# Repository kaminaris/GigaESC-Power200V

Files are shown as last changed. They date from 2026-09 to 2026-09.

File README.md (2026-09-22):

# GigaPower200V

Compact 50 × 20 mm non-isolated power-supply module for the modular GigaESC platform, intended for the 200 V version. Provides 12 V, 5 V and 3.3 V rails through a separate output connector.

## Board views

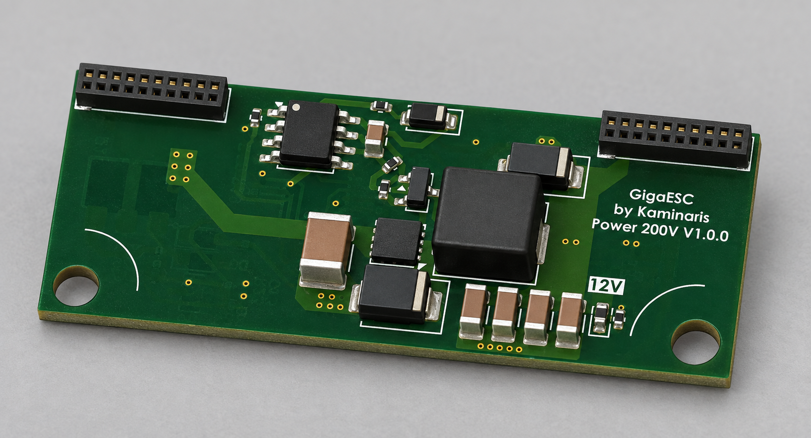
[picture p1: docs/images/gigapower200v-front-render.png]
GigaPower200V front view


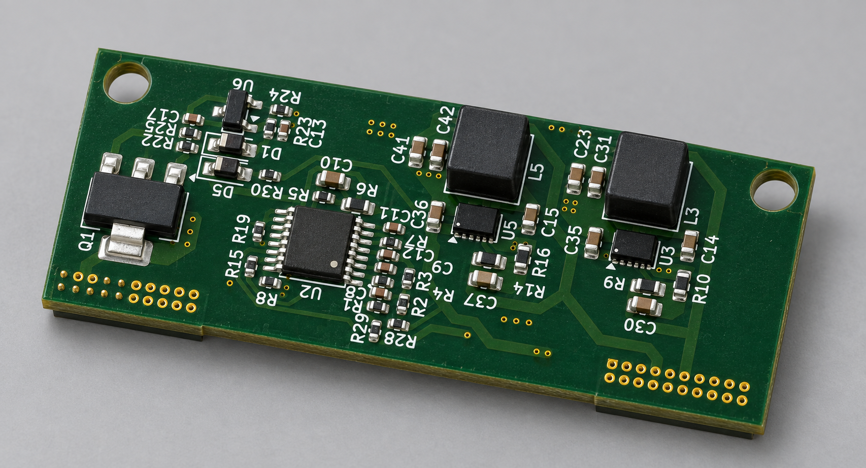
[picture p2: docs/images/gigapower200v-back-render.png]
GigaPower200V back view


## Hardware

- TL494 PWM controller, IR2181 gate driver and TL431 reference circuitry.
- Two AP63356DV buck regulators for the lower-voltage rails.
- Two 2×10 connectors separating input and output connections.
- Common ground between input and outputs; no galvanic isolation.

## Connector summary

| Connector | Pins | Signal |
|---|---|---|
| J1 input | 3, 5 | VIN |
| J1 input | 17–20 | GND |
| J2 output | 3, 4 | 12 V |
| J2 output | 7, 8 | 5 V |
| J2 output | 11, 12 | 3.3 V |
| J2 output | 1, 2, 5, 6, 9, 10, 13–16, 19, 20 | GND |

Remaining connector pins are unconnected in the schematic. Use the current schematic as the authoritative pinout.

## Project

Open `GigaPower200V.kicad_pro` in KiCad 10. Schematic and layout are in `GigaPower200V.kicad_sch` and `GigaPower200V.kicad_pcb`. Local libraries are included; keep the connector STEP model alongside the project.

The project name describes the intended voltage class, not a measured operating limit. Input range, output loading and thermal performance require hardware validation. The inherited `LM5164_DESIGN.md` describes an earlier design and is not documentation for the current TL494 implementation.

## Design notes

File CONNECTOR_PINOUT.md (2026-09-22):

# GigaControl connector pinout

Three 2x10, 1.00 mm pitch straight female sockets on the control card: Hanxia HX PM1.0-2x10P ZC, LCSC C22465702. Matching proposed right-angle male headers on the power board: HX PZ1.0-2x10P WZ, C22465711.

F.Cu view: J1, J2, J3 left to right; odd row at Y=88.1, even row at Y=87.1. Pad-1 X positions: 138.1, 150.1, 162.1 mm. Three sockets span 34.4 mm of nominal housing length. Phase contacts and connector positions are preserved. Three reserved interface contacts have been reclaimed for GND; active peripheral signals retain their numeric sequence while shifting pins.

J3 GND contacts: pins 1, 10, and 20 (left, middle, right). Peripheral remapping starts at J2 pin 17; the table below is authoritative.

| Column | Connector | Odd pin | Signal | Even pin | Signal |
|---:|---|---:|---|---:|---|
| 1 | J1 | 1 | `+5V` | 2 | `GND` |
| 2 | J1 | 3 | `+3.3V` | 4 | `IN V` |
| 3 | J1 | 5 | `POWER STAGE DISABLE` | 6 | `POWER STAGE LOCKOUT` |
| 4 | J1 | 7 | `MOSTEMP3` | 8 | `GND` |
| 5 | J1 | 9 | `H3` | 10 | `GND` |
| 6 | J1 | 11 | `L3` | 12 | `GND` |
| 7 | J1 | 13 | `CURR3 FILTERED` | 14 | `GND` |
| 8 | J1 | 15 | `VSENSE3` | 16 | `GND` |
| 9 | J1 | 17 | `MOSTEMP2` | 18 | `GND` |
| 10 | J1 | 19 | `H2` | 20 | `GND` |
| 11 | J2 | 1 | `L2` | 2 | `GND` |
| 12 | J2 | 3 | `CURR2 FILTERED` | 4 | `GND` |
| 13 | J2 | 5 | `VSENSE2` | 6 | `GND` |
| 14 | J2 | 7 | `MOSTEMP1` | 8 | `GND` |
| 15 | J2 | 9 | `H1` | 10 | `GND` |
| 16 | J2 | 11 | `L1` | 12 | `GND` |
| 17 | J2 | 13 | `CURR1 FILTERED` | 14 | `GND` |
| 18 | J2 | 15 | `VSENSE1` | 16 | `GND` |
| 19 | J2 | 17 | `USBD-` | 18 | `USBD+` |
| 20 | J2 | 19 | `SWDIO` | 20 | `HALL3 IN` |
| 21 | J3 | 1 | `GND` | 2 | `SERVO` |
| 22 | J3 | 3 | `I2C2 SDA{slash}USART3 RX` | 4 | `ESP-RX` |
| 23 | J3 | 5 | `SPI1-MISO-ADC2` | 6 | `SPI1-SCK-ADC` |
| 24 | J3 | 7 | `HALL1 IN` | 8 | `HALL-VOLTAGE` |
| 25 | J3 | 9 | `I2C2 SCL{slash}USART3 TX` | 10 | `GND` |
| 26 | J3 | 11 | `SPI1-NSS` | 12 | `NRST` |
| 27 | J3 | 13 | `HALL2 IN` | 14 | `ESP-TX` |
| 28 | J3 | 15 | `SPI1-MOSI` | 16 | `IN-CANL` |
| 29 | J3 | 17 | `TEMPMOTOR IN` | 18 | `IN-CANH` |
| 30 | J3 | 19 | `SWCLK` | 20 | `GND` |

Phase 3: columns 4-8; phase 2: 9-13; phase 1: 14-18. All 41 active non-ground signals retained, with 19 ground contacts. RESERVED1/2/3 no longer cross the connector; their MCU-side circuitry is unchanged.

## Mechanical notes

- Local socket footprint follows the Hanxia drawing: body 10.4 x 2.5 mm, height 2 mm, 1 x 1 mm pin grid, 0.50 mm finished holes. Pads are 0.8 mm; courtyard includes body tolerance plus assembly clearance. No 3D model is assigned.
- Numbering is the project logical odd/even convention; the unkeyed manufacturer drawing does not define pin 1. Power-board mating placement must map contacts physically, not copy the control footprint rotation blindly.
- Upright card inserts horizontally with right-angle male pins on the horizontal power board. Allow withdrawal clearance and provide a guide/support; do not rely on the three connectors for vibration support.
- Header drawing has 0.30 mm square contacts and 2.00 mm nominal horizontal exposed tips; the 1.8 mm dimension is vertical tail projection. Socket drawing does not specify a recommended mating-pin insertion range; verify engagement with samples before manufacture.
- Connector fanout remains unfinished; moving pads does not reroute existing traces. No raw battery voltage crosses the interface.

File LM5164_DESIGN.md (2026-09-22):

# LM5164 design — 20–90 V to nominal 12 V / 1 A

Schematic design pass, 2026-09-16. Not a production-qualified supply. Typical reported system consumption is about 2 W; retain 12 W output design target including downstream converters. No PCB changes in this pass.

## Selected components and inventory

| References | Value / part | Inventory / decision |
|---|---|---|
| U1 | LM5164DDAR | Not found; order |
| L4 | 68 uH MSS1210-683MEB | WEBENCH baseline, not stocked; correct Coilcraft footprint replaces unrelated 5 mm placeholder |
| R11 | 100k 0603WAF1003T5E | Stock C25803, R20, qty 200 |
| R12 | 453k RC0603FR-07453KL | WEBENCH value, not stocked |
| R13 | 50k RT0603BRD0750KL | WEBENCH value, not stocked |
| R17 / R18 | 150k + 200k, 0603 | Stock C22807 / C25811, R20; total 350k instead of WEBENCH 357k |
| C2 / C6 | 2.2 nF 50 V X7R 0603B222K500NT | Stock C1604, C1, qty 100 |
| C7 | 47 pF NP0 CC0603FRNPO0BN470 | Stock C527044, C1, qty 50 |
| C1 / C4 | 10 uF 100 V X7R FS32X106K101EGG, 1210 | Stock C5156756, C2, qty 32. PROVISIONAL pending DC-bias data |
| C3 / C5 | 22 uF 25 V X5R CL31A226KAHNNNE, 1206 | Stock C12891, C2, qty 10. Verify effective capacitance and local temperature; X5R is rated only to 85 C |

Counts are database qty, not qty minus inUse. No inventory was reserved or modified. The stock CYA0650-68UH (C5189964, qty 4, inUse 1, bin L1) remains an alternative, not an approved replacement: its specific datasheet could not be retrieved and the accessible family sheet does not list 68 uH. The 1.8 A catalog rating alone does not establish saturation margin. The other stocked 68 uH YSPI1365 is large and also needs a verified saturation specification.

## Calculated operating points

First-order CCM calculations at nominal 300 kHz, 68 uH, 12 V. These are calculations, not simulations or measurements.

| VIN | Duty | On time | Inductor ripple p-p | Peak at 1 A | Injected ramp estimate |
|---|---:|---:|---:|---:|---:|
| 20 V | 0.600 | 2.00 us | 0.235 A | 1.118 A | 20.8 mV |
| 48 V | 0.250 | 0.833 us | 0.441 A | 1.221 A | 39.0 mV |
| 90 V | 0.133 | 0.444 us | 0.510 A | 1.255 A | 45.0 mV |

At minus 20% inductance, 90 V ripple becomes 0.637 A p-p and peak 1.319 A, before switching-frequency tolerance, temperature, or DC-bias loss of inductance. Qualify saturation against the regulator current limit, not merely 1.319 A normal-load peak.

The 350k * 2.2nF network has a 770 us time constant, 2% below WEBENCH. Splitting it limits nominal 90 V switching-step resistor stress to about 33.4 V / 44.6 V across 150k / 200k once the ramp node is near 12 V; at startup with the ramp node near zero the split is about 38.6 V / 51.4 V. Check overshoot and actual resistor pulse ratings during bring-up.

The divider's ideal zero-ripple setpoint is 12.072 V. Ripple injection, reference/divider tolerances and operating mode affect the actual DC output. Do not describe this as precision 12.000 V. The 47 pF coupling choice is retained from WEBENCH; transient response needs bench validation with the downstream converters attached.

At roughly 0.167 A load, the LM can enter discontinuous / pulse-skipping operation at higher VIN. The 1 A current target does not imply continuous-conduction operation at typical load. The prior 9 mW small-inductor loss estimate excludes ripple; it is not a complete light-load loss prediction.

## Qualification and integration remaining

- C1/C4 must retain at least 2.2 uF total at 90 V, with tolerance, temperature and aging allowed for. 20 uF nominal is NOT evidence of that. No usable part-specific bias curve was obtained. If not verified, use a documented higher-voltage capacitor rather than relying on this provisional stock selection. WEBENCH's 450 V parts were not copied into the small-board design.
- C3/C5 target at least 10 uF effective total at 12 V. At that assumed minimum, nominal worst-case capacitive ripple is about 21 mV p-p (excluding ESR/transients). Stock X5R parts constrain local temperature to <=85 C; use X7R replacements if that is insufficient.
- 90 V DC leaves only 10 V to the IC's 100 V absolute maximum. VBAT is currently an explicit local net, not connected to the unassigned J2 connector. Battery leads, main-board bulk capacitance, hot-plug damping and regeneration overshoot must be addressed at integration. Do not assume an ordinary 90 V TVS clamps below 100 V.
- EN remains tied to VIN as in WEBENCH. No battery undervoltage cutoff is implied by the 20 V design minimum. PGOOD intentionally remains unconnected.
- Ground EP and keep the input switching loop short. Route the divider/ripple network away from SW copper and return it to quiet IC ground. Validate output ripple, load steps, startup, fault behavior and temperatures at both input extremes.
- PCB placement/routing and connector pin assignment are not part of this schematic pass. Reconcile the schematic with the PCB after component qualification.

## Sources

- User-provided WBSchematicLM5164DDAR.svg and WBBOMDesignLM5164DDAR.csv.
- TI LM5164 datasheet: https://www.ti.com/lit/ds/symlink/lm5164.pdf
- Coilcraft baseline inductor: https://www.coilcraft.com/getmedia/f1a1bc5f-bdff-42f8-9ca8-1a0fb1d5094f/MSS1210.pdf
- Samsung stock output capacitor: https://product.samsungsem.com/mlcc/CL31A226KAHNNN.do
- Read-only local bommanager inventory snapshot.

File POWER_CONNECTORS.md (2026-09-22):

# GigaPower100V supply module — J1 / J2 pinout

Two 2x10, 1.00 mm pitch connectors (Hanxia HX PM1.0-2x10P ZC, LCSC C22465702; mating
HX PZ1.0-2x10P WZ, C22465711). **J1 carries the battery bus, J2 carries only low voltage.**

Connector ratings from the LCSC listing: 750 mA per contact, catalogue rated voltage 500 V,
−40…+105 °C, 1 x 1 mm contact grid, gold-plated phosphor bronze.

## J1 — HV input

| Col | Odd | Signal | Even | Signal |
|---:|---:|---|---:|---|
| 1 | 1 | `VBAT` | 2 | `VBAT` |
| 2 | 3 | *NC* | 4 | *NC* |
| 3 | 5 | *NC* | 6 | *NC* |
| 4 | 7 | *NC* | 8 | *NC* |
| 5 | 9 | *NC* | 10 | *NC* |
| 6 | 11 | *NC* | 12 | *NC* |
| 7 | 13 | *NC* | 14 | *NC* |
| 8 | 15 | *NC* | 16 | *NC* |
| 9 | 17 | `GND` | 18 | `GND` |
| 10 | 19 | `GND` | 20 | `GND` |

- `VBAT` is paired because 12 W at the 20 V design minimum draws about 0.7 A, right at one
  contact's 750 mA rating. Four `GND` contacts carry the 0.7 A return with margin.
- Columns 2-8 are a deliberate gap: 8 mm contact to contact, about 7.2 mm pad edge to pad edge,
  against roughly 0.71 mm creepage required at 100 V and 3.2 mm at 650 V (PD2, group IIIa).
- **The gap only delivers its full distance if those contacts are physically absent.** A
  populated connector leaves 14 floating contacts in the path; floating metal can assume any
  potential, so each 1 mm segment must meet the full creepage requirement on its own. That
  passes at 100 V and fails at 650 V.
- The module is **not isolated**: `GND` is battery negative. The whole low-voltage side sits at
  battery-negative potential, so touch safety is the enclosure's job, not this connector's.

## J2 — LV output

| Col | Odd | Signal | Even | Signal |
|---:|---:|---|---:|---|
| 1 | 1 | `GND` | 2 | `GND` |
| 2 | 3 | `+12V` | 4 | `+12V` |
| 3 | 5 | `GND` | 6 | `GND` |
| 4 | 7 | `+5V` | 8 | `+5V` |
| 5 | 9 | `GND` | 10 | `GND` |
| 6 | 11 | `+3.3V` | 12 | `+3.3V` |
| 7 | 13 | `GND` | 14 | `GND` |
| 8 | 15 | `GND` | 16 | `GND` |
| 9 | 17 | *NC — reserved* | 18 | *NC — reserved* |
| 10 | 19 | `GND` | 20 | `GND` |

- Every rail uses a pair of contacts (1.5 A) with a ground column beside it, so the supply and
  return currents stay adjacent.
- 12 ground contacts give about 9 A of return capacity, well past the sum of the three rails.
- Pins 17/18 are reserved for `PGOOD` and a divided `VBAT-SENSE` (≤ 3.3 V). Neither circuit
  exists yet: the LM5164's PGOOD is still unconnected and there is no sense divider.

## Voltage limits — read before reusing at 650 V

This pinout is qualified for the **100 V family only**.

| Working voltage | Creepage needed (PD2, group IIIa) | Available |
|---|---|---|
| 100 V | ≈ 0.71 mm | 1.0 mm contact-to-contact, 1.2 mm pad-to-pad across the gap |
| 650 V | ≈ 3.2 mm (≈ 1.8 mm if conformal coated, treated as PD1) | unchanged |

For a 650 V+ version:

1. 650 V exceeds the connector's 500 V catalogue rating, so pin spacing alone cannot make it
   compliant. The HV entry needs a different, properly rated connector or soldered leads.
2. The floating contacts between HV and GND subdivide the creepage path, so simply skipping
   more columns does not buy the full distance.
3. The LM5164 is a 100 V part; a 650 V bus needs a different converter topology anyway.

Keep J2's pinout unchanged across the family. Only the HV entry changes.

## Assembly hazard

J1 and J2 are the same connector, so a swapped cable puts the battery bus straight onto the
3.3 V rail. Before building harnesses, do one of: use a different connector family or pin count
for J1, key/block the housings, or place them far enough apart that no harness can reach the
wrong socket.

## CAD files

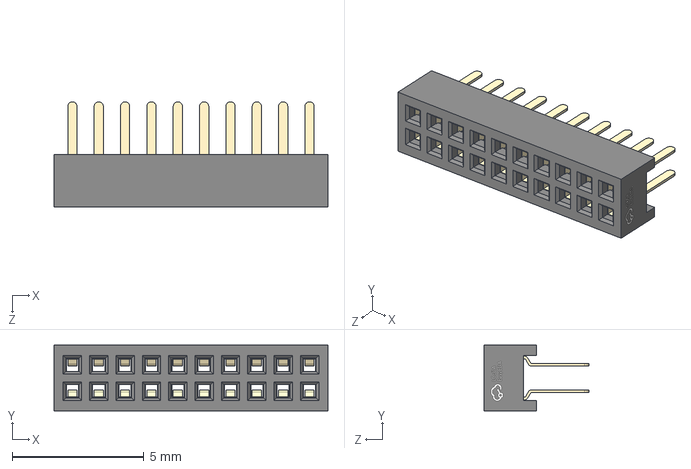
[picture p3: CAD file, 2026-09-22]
HDR-TH_20P-P1.00-V-F-R2-C10-S1.00.step
10.4 x 2.50 x 4.00 mm

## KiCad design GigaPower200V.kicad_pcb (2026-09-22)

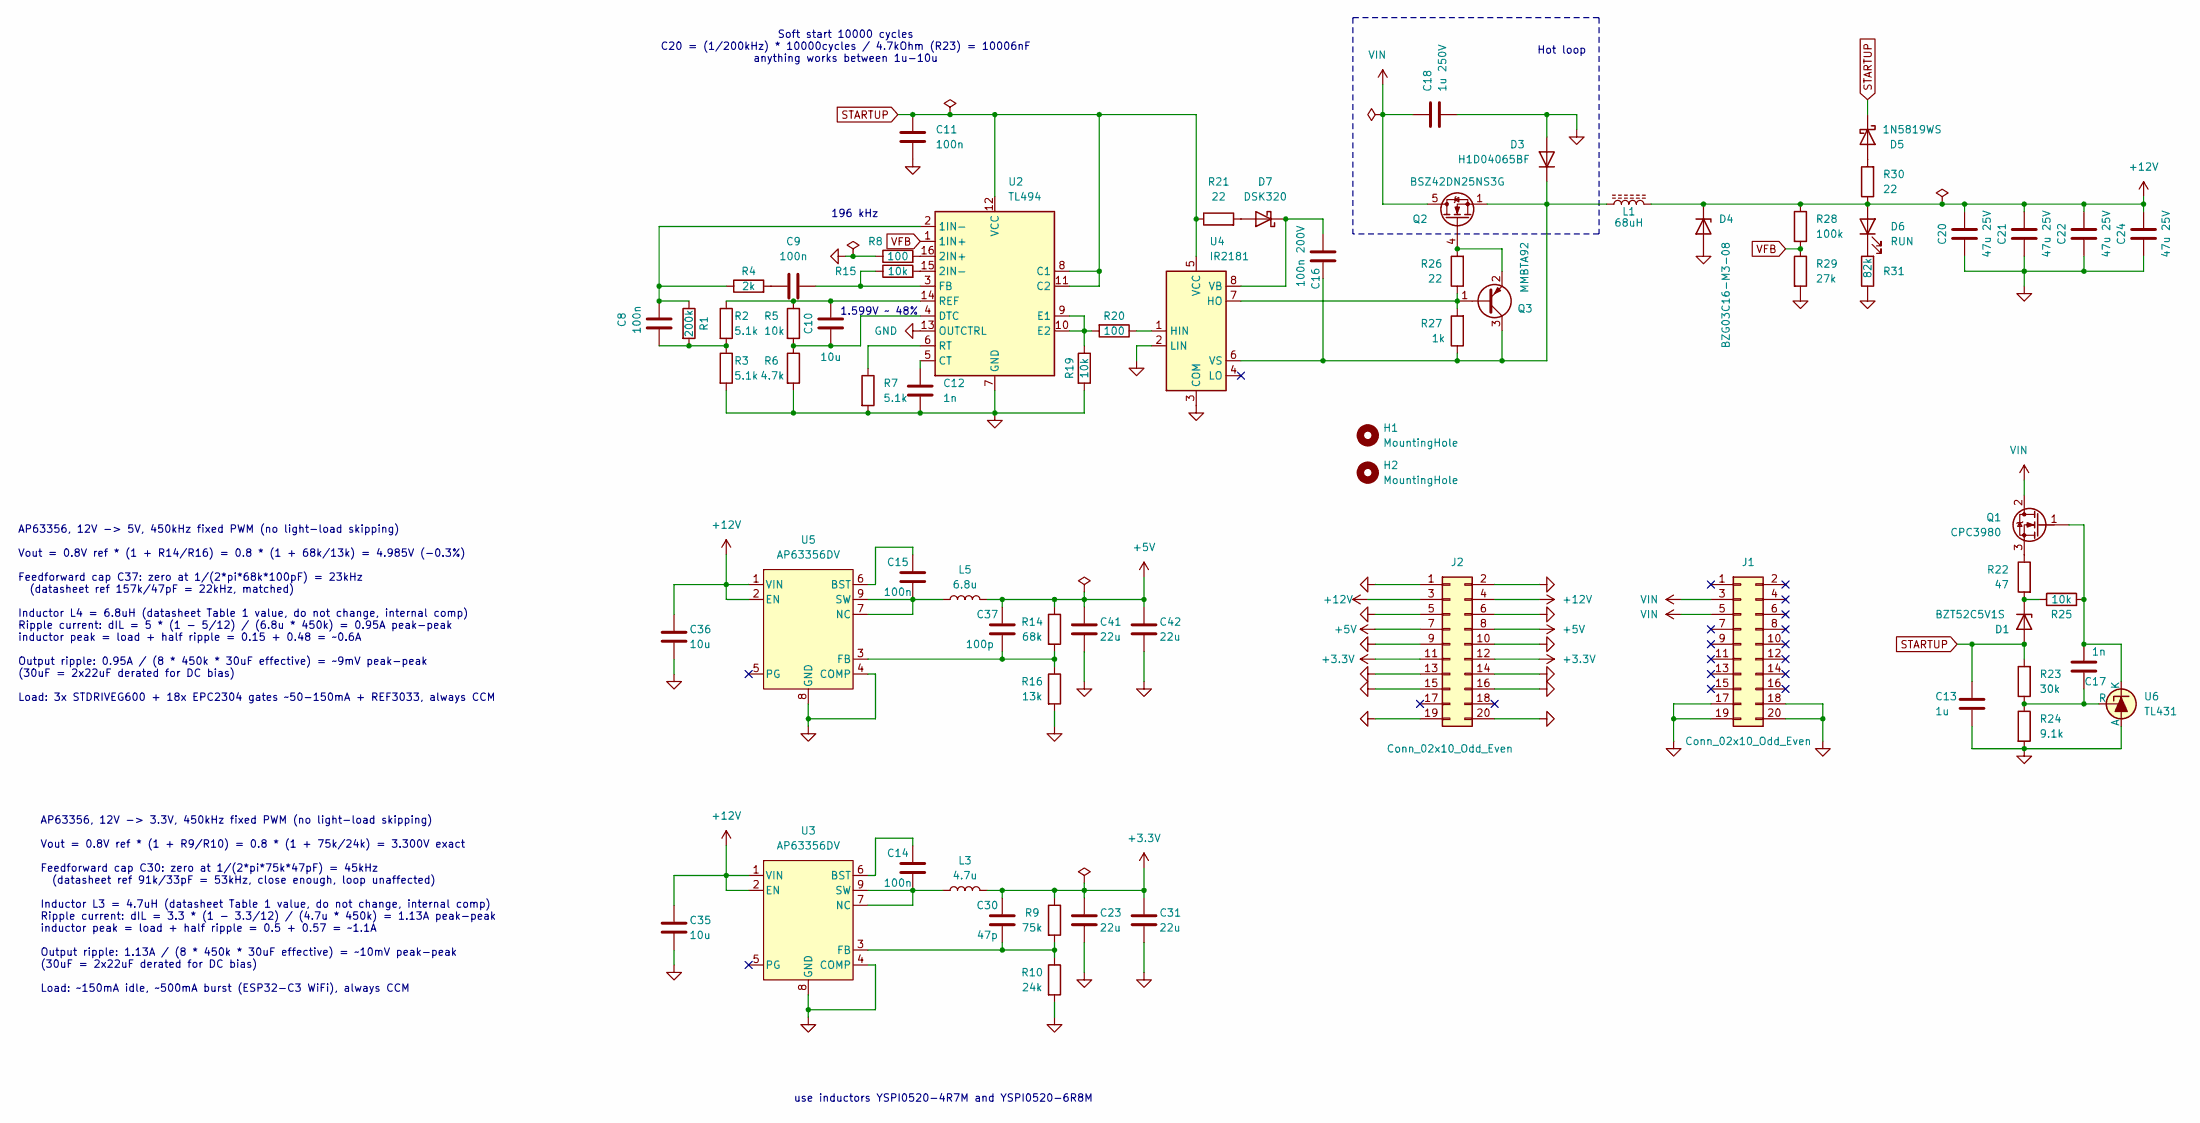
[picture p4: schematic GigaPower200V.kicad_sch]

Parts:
C8, C9, C11: 100n; C_0402_1005Metric; MPN C307331; Mouser 581-08055C104KAT4A
C10, C35, C36: 10u; C_0603_1608Metric; MPN C96446
C12, C17: 1n; C_0402_1005Metric; MPN C1523; Mouser 80-C0603C102K5R7081
C13: 1u; C_0402_1005Metric; MPN C52923; Mouser 581-08055C104KAT4A
C14, C15: 100n; C_0603_1608Metric; MPN C14663; Mouser 187-CL21B104KBFNNNE
C16: 100n 200V; C_0805_2012Metric; MPN C784084
C18: 1u 250V; C_1812_4532Metric; MPN C381468
C20, C21, C22, C24: 47u 25V; C_1206_3216Metric; MPN C403725
C23, C31, C41, C42: 22u; C_0603_1608Metric; MPN C86295
C30: 47p; C_0603_1608Metric; MPN C527044; Mouser 187-CL21B104KBFNNNE
C37: 100p; C_0603_1608Metric; MPN C14858; Mouser 187-CL21B104KBFNNNE
D1: BZT52C5V1S; D_SOD-323_HandSoldering; MPN C2886317
D3: H1D04065BF; D_SMB; MPN C52145208
D4: BZG03C16-M3-08; D_SMA; MPN C5224074; Mouser 821-1SMB5928
D5: 1N5819WS; D_SOD-323_HandSoldering; MPN C191023
D6: RUN; D_0603_1608Metric; MPN C2290
D7: DSK320; D_SOD-123; MPN C5290222; Mouser 750-SS520B-HF
H1, H2: MountingHole; MountingHole_3.2mm_M3_DIN965
J1, J2: Conn_02x10_Odd_Even; Hanxia_HX_PM1.0-2x10P_ZC; MPN HX PM1.0-2x10P ZC; LCSC C22465702
L1: 68uH; L_Chilisin_BMRB00060650; MPN C5189964
L3: 4.7u; L_Sunlord_SWPA5040S; MPN C341032; Mouser C341032
L5: 6.8u; L_Sunlord_SWPA5040S; MPN C36411; Mouser C341032
Q1: CPC3980; SOT-223-3_TabPin2; MPN C5373317
Q2: BSZ42DN25NS3G; Diodes_PowerDI3333-8; MPN C6869298
Q3: MMBTA92; SOT-23; MPN C916395
R1: 200k; R_0402_1005Metric; MPN C25764; Mouser 603-RC0805FR-0744K2L
R2, R3, R7: 5.1k; R_0402_1005Metric; MPN C25905; Mouser 603-RC0805FR-0744K2L
R4: 2k; R_0402_1005Metric; MPN C4109; Mouser 603-RC0805FR-0744K2L
R5: 10k; R_0402_1005Metric; MPN C25744
R6: 4.7k; R_0603_1608Metric; MPN C23162
R8: 100; R_0402_1005Metric; MPN C25076; Mouser 603-RC0805FR-0744K2L
R9: 75k; R_0603_1608Metric; MPN C23242
R10: 24k; R_0603_1608Metric; MPN C23352
R14: 68k; R_0603_1608Metric; MPN C23231
R15: 10k; R_0402_1005Metric; MPN C25744; Mouser 603-RC0805FR-0744K2L
R16: 13k; R_0603_1608Metric; MPN C22797
R19, R25: 10k; R_0402_1005Metric; MPN C25744; Mouser 71-CRCW080520R0FKEAC
R20: 100; R_0402_1005Metric; MPN C25076; Mouser 71-CRCW080520R0FKEAC
R21, R26, R30: 22; R_0402_1005Metric; MPN C25092; Mouser 71-CRCW080520R0FKEAC
R22: 47; R_0402_1005Metric; MPN C25118
R23: 30k; R_0402_1005Metric; MPN C25776; Mouser 71-CRCW080520R0FKEAC
R24: 9.1k; R_0402_1005Metric; MPN C25926
R27: 1k; R_0402_1005Metric; MPN C11702; Mouser 71-CRCW080520R0FKEAC
R28: 100k; R_0402_1005Metric; MPN C25741
R29: 27k; R_0402_1005Metric; MPN C25771
R31: 82k; R_0402_1005Metric; MPN C4142; Mouser 603-AC0805JR-0710KL
U2: TL494; TSSOP-16_4.4x5mm_P0.65mm; MPN C163520; JLCRotOffset 0
U3, U5: AP63356DV; V-DFN3020-13_DIO; MPN C2157973
U4: IR2181; SOIC-8_3.9x4.9mm_P1.27mm; MPN C37524; JLCRotOffset 0
U6: TL431; SOT-23; MPN C181103

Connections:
+3.3V: C23.1, C30.2, C31.1, J2.11, J2.12, L3.2, R9.1
+5V: C37.2, C41.1, C42.1, J2.7, J2.8, L5.2, R14.1
+12V: C20.1, C21.1, C22.1, C24.1, C35.1, C36.1, D4.1 (K), D6.2 (A), J2.3, J2.4, L1.2, R28.1, R30.1, U3.1 (VIN), U3.2 (EN), U5.1 (VIN), U5.2 (EN)
GND: C11.2, C12.2, C13.2, C18.2, C20.2, C21.2, C22.2, C23.2, C24.2, C31.2, C35.2, C36.2, C41.2, C42.2, D3.2 (A), D4.2 (A), J1.17, J1.18, J1.19, J1.20, J2.1, J2.2, J2.5, J2.6, J2.9, J2.10, J2.13, J2.14, J2.15, J2.16, J2.19, J2.20, R3.2, R6.2, R7.2, R8.1, R10.2, R16.2, R19.2, R24.2, R29.2, R31.1, U2.7 (GND), U2.13 (OUTCTRL), U3.4 (COMP), U3.8 (GND), U4.2 (LIN), U4.3 (COM), U5.4 (COMP), U5.8 (GND), U6.3 (A)
unnamed: C8.2, R1.2, R2.2, R3.1
unnamed: C9.1, R4.2
unnamed: D1.1 (K), R22.2, R25.1
unnamed: C16.2, D3.1 (K), L1.1, Q2.1 (S), Q2.2 (S), Q2.3 (S), Q3.3 (C), R27.1, U4.6 (VS)
unnamed: D5.2 (A), R30.2
unnamed: D6.1 (K), R31.2
unnamed: D7.2 (A), R21.2
unnamed: C16.1, D7.1 (K), U4.8 (VB)
unnamed: C17.1, Q1.1 (G), R25.2, U6.2 (K)
unnamed: Q1.3 (S), R22.1
unnamed: Q2.4 (G), Q3.2 (E), R26.2
unnamed: Q3.1 (B), R26.1, R27.2, U4.7 (HO)
unnamed: C8.1, R1.1, R4.1, U2.2 (1IN-)
unnamed: R8.2, U2.16 (2IN+)
unnamed: R15.2, U2.15 (2IN-)
unnamed: C12.1, U2.5 (CT)
unnamed: C10.2, R5.2, R6.1, U2.4 (DTC)
unnamed: R19.1, R20.2, U2.9 (E1), U2.10 (E2)
unnamed: C9.2, R15.1, U2.3 (FB)
unnamed: C10.1, R2.1, R5.1, U2.14 (REF)
unnamed: R7.1, U2.6 (RT)
unnamed: C14.2, U3.6 (BST)
unnamed: C30.1, R9.2, R10.1, U3.3 (FB)
unnamed: C14.1, L3.1, U3.7 (NC), U3.9 (SW)
unnamed: R20.1, U4.1 (HIN)
unnamed: C15.2, U5.6 (BST)
unnamed: C37.1, R14.2, R16.1, U5.3 (FB)
unnamed: C15.1, L5.1, U5.7 (NC), U5.9 (SW)
unnamed: C17.2, R23.1, R24.1, U6.1 (R)
STARTUP: C11.1, C13.1, D1.2 (A), D5.1 (K), R21.1, R23.2, U2.8 (C1), U2.11 (C2), U2.12 (VCC), U4.5 (VCC)
VFB: R28.2, R29.1, U2.1 (1IN+)
VIN: C18.1, J1.3, J1.5, Q1.2 (D), Q2.5 (D)

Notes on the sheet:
Hot loop
AP63356, 12V -> 3.3V, 450kHz fixed PWM (no light-load skipping) Vout = 0.8V ref * (1 + R9/R10) = 0.8 * (1 + 75k/24k) = 3.300V exact Feedforward cap C30: zero at 1/(2*pi*75k*47pF) = 45kHz (datasheet ref 91k/33pF = 53kHz, close enough, loop unaffected) Inductor L3 = 4.7uH (datasheet Table 1 value, do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
use inductors YSPI0520-4R7M and YSPI0520-6R8M
196 kHz
AP63356, 12V -> 5V, 450kHz fixed PWM (no light-load skipping) Vout = 0.8V ref * (1 + R14/R16) = 0.8 * (1 + 68k/13k) = 4.985V (-0.3%) Feedforward cap C37: zero at 1/(2*pi*68k*100pF) = 23kHz (datasheet ref 157k/47pF = 22kHz, matched) Inductor L4 = 6.8uH (datasheet Table 1 value, do not change, intern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
1.599V ~ 48%
Soft start 10000 cycles C20 = (1/200kHz) * 10000cycles / 4.7kOhm (R23) = 10006nF anything works between 1u-10u

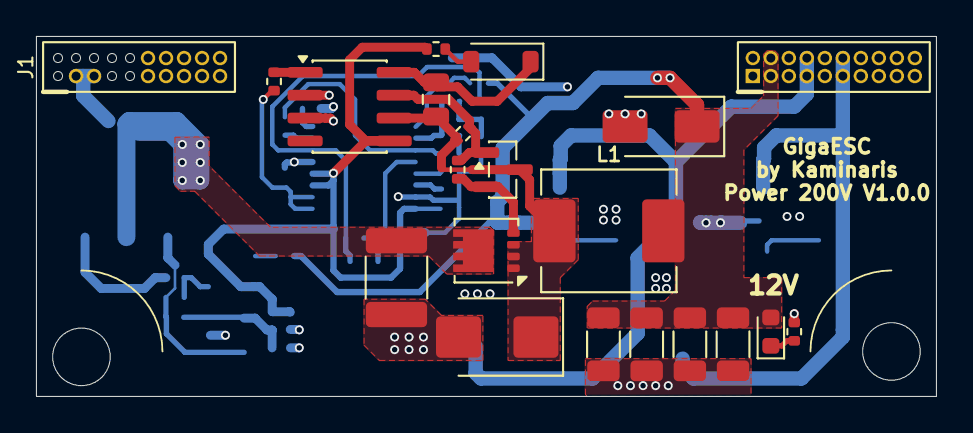
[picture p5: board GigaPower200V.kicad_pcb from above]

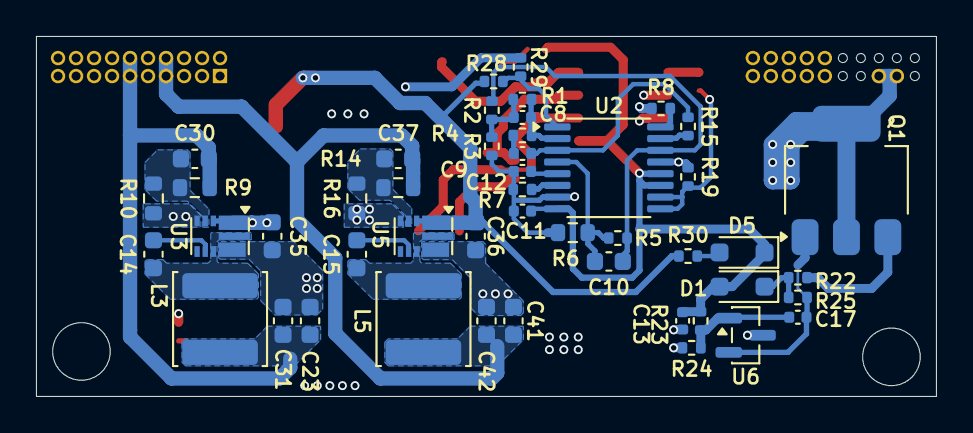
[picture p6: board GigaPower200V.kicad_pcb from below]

Board: 4 copper layers, 50.0 x 20.0 mm, 70 parts (47 on the bottom side), 36 nets.
